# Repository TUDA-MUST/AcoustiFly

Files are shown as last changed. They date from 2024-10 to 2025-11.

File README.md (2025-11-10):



# AcoustiFly, a single transducer Acoustic Levitator






Unlock the Power of Sound: Explore Acoustic Levitation with Ease and Precision.
This project focuses on the development of an acoustic levitator, a fascinating technology capable of suspending small objects in mid-air using ultrasonic waves.
It is:
* **Low Cost:** Affordable and accessible to everyone -> approximately between 15-25 USD per unit
* **Easy to Build:** Simple setup with readily available components
* **Open Source:** Free to use, modify, and distribute
* **Mobile:** Battery powered operation possible
* **Adjustable:** Distance between transducer and reflector can be adjusted, thus stability can be tuned

This repository provides all the necessary resources, including code, schematics, and documentation, to build and experiment with your very own acoustic levitation system.

Move

***

## Table of Contents

- [Introduction](#introduction)
- [Installation](#installation)
- [Assemby](#assembly)
- [Usage](#usage)
- [Contributing](#contributing)
- [License](#license)
- [Frequently Asked Questions \(FAQ\)](#frequently-asked-questions-faq)

## Introduction

Our repository is dedicated to showcasing a method of acoustic levitation using a single transducer and a reflector. Acoustic levitation, also known as acoustic trapping, is a fascinating technique that allows objects to float in mid-air using sound waves.

In our approach, we utilize a single transducer, which emits high-frequency sound waves, and a carefully designed reflector. 
The transducer generates an acoustic field that interacts with the reflector to create standing waves within a confined region. 
These standing waves produce regions of high and low pressure, forming what is known as an "acoustic pressure node".

When an object is placed at a specific position within the acoustic pressure node, the forces exerted by the surrounding sound waves counteract the gravitational force, resulting in levitation. By precisely adjusting the distance of the transducer and the reflector, we can control the levitation height and stability of objects.

This unique approach offers several advantages. 
Firstly, it simplifies the setup by using only a single transducer and a reflector, reducing complexity and cost. 
Secondly, it enables precise control over the levitation process, allowing for manipulation and positioning of objects with great accuracy. 
Lastly, it opens up possibilities for various applications, including material handling, microfluidics, and scientific experiments.

In our repository, we provide detailed documentation, source code, and demonstrations to help you understand and implement this acoustic levitation technique.
 Whether you are a researcher, teacher, hobbyist, or enthusiast, we invite you to explore our repository, contribute to its development, and unlock the potential of acoustic levitation with a single transducer and a reflector.

**Join us on this exciting journey of harnessing the power of sound waves to defy gravity. Visit [our homepage](https://www.etit.tu-darmstadt.de/must/home_must/index.en.jsp) to delve into our research and learn more about our team.**

## Assembly
To assemble the Acoustifly you will need the following components:

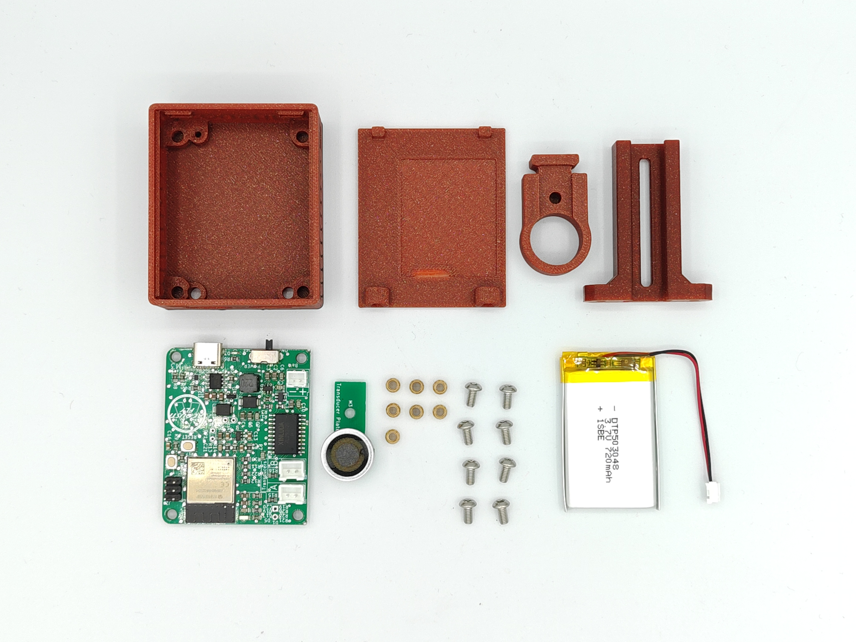
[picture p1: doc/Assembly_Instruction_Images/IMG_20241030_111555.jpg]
Acoustifly Components


* **3D-printed:**

  Base, Battery-Cover, Transducer-Holder, Vertical profile
* **Electrical Components:**

  UT-1640K-TT-2-R Transducer, Transducer PCB, Acoustifly PCB, EXP-T11-020 3.7V 720mAh Lithium Polymer Battery with JST-PH connector,
* **Others:**

  Ruthex M3s threaded inserts, M3 screws

### Instructions:
1. To install the threaded inserts you need to heat them up to 230°C. Best is to use a soldering tip to melt them into the 3D-printed parts.

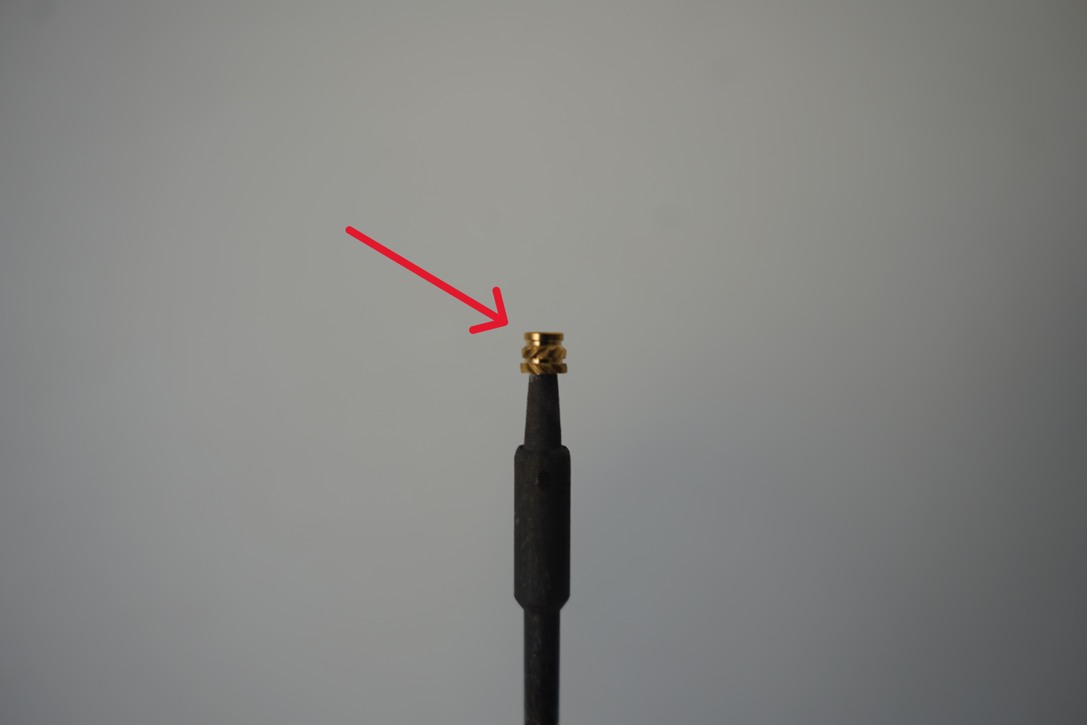
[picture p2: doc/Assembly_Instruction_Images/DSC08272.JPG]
Solderint Tip with threaded insert
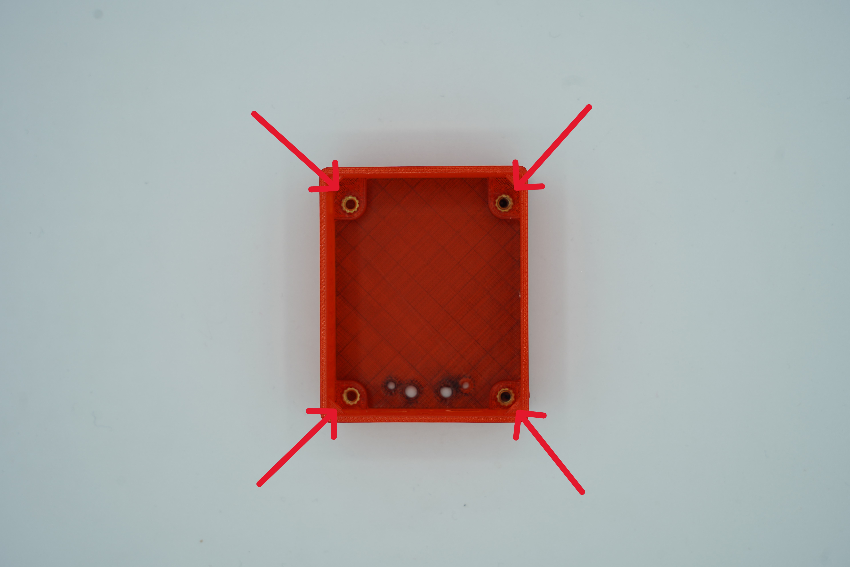
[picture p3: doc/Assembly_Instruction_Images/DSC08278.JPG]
Base with threaded insert
   
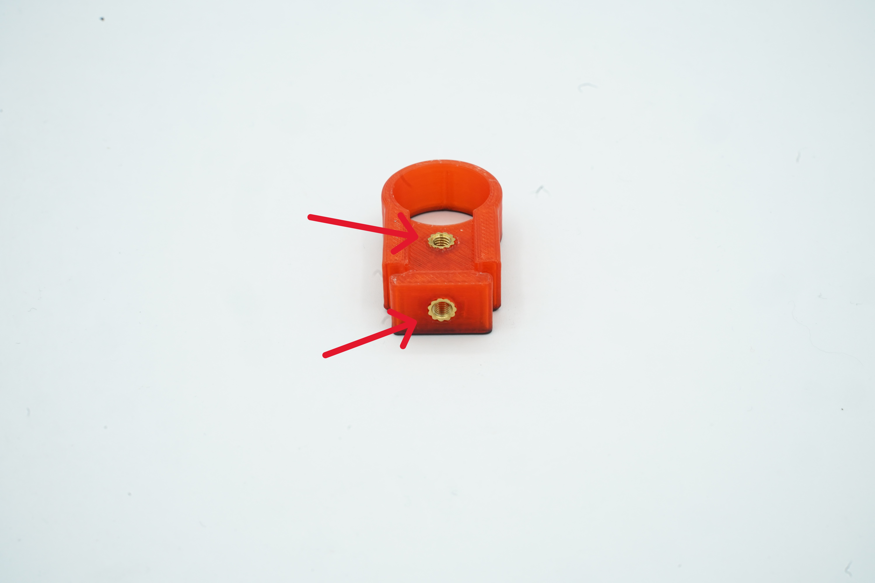
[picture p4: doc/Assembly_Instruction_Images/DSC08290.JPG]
Transducer holder with threaded inserts
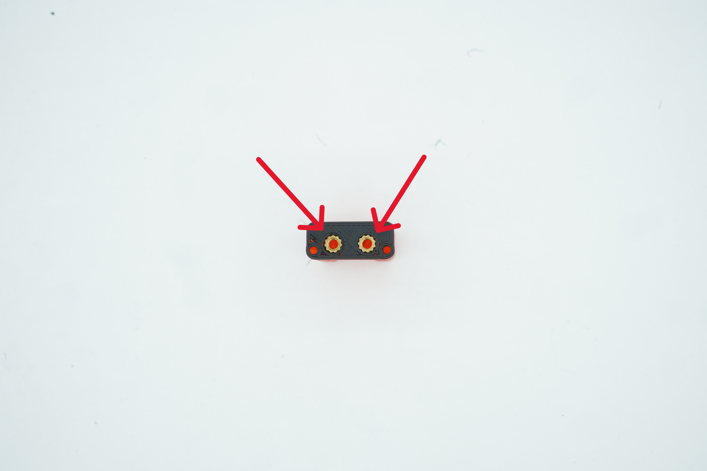
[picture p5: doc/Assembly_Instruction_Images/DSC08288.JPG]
Vertical Profile with threaded insert
   
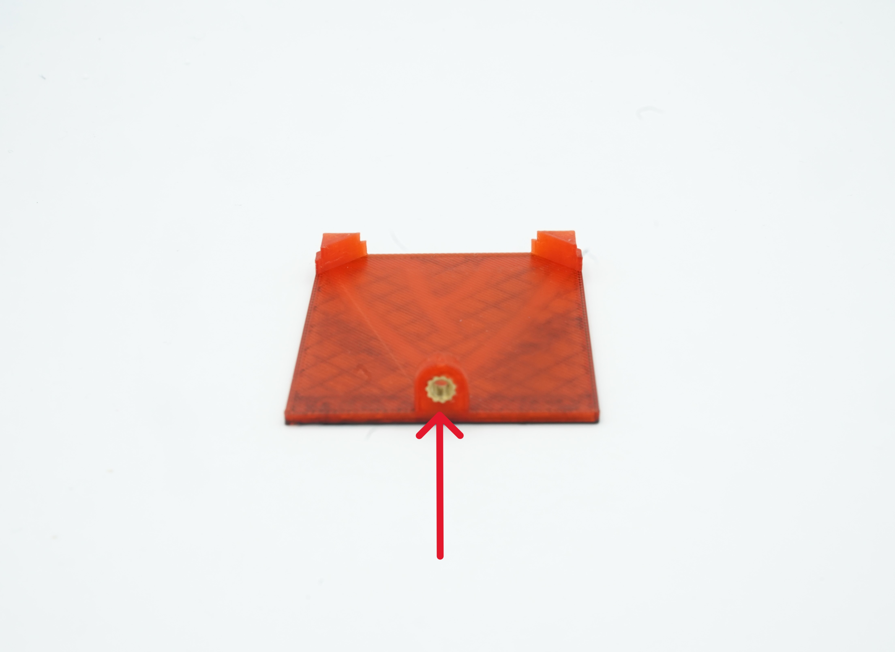
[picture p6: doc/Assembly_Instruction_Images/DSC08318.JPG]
Battery Cover with threaded insert
  

2. Mount the Transducer PCB with the Tranducer on the Transducer holder:

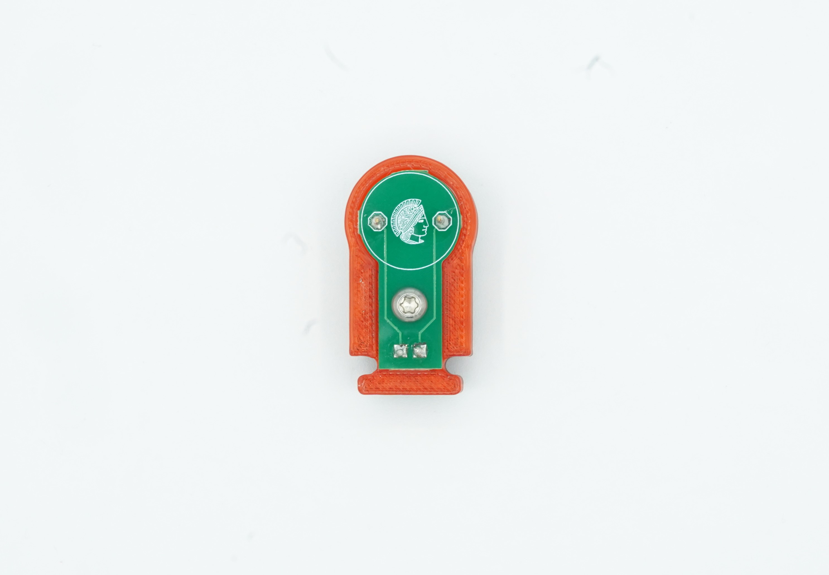
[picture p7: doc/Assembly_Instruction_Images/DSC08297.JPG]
  

3. Attach it to the vertical profile:

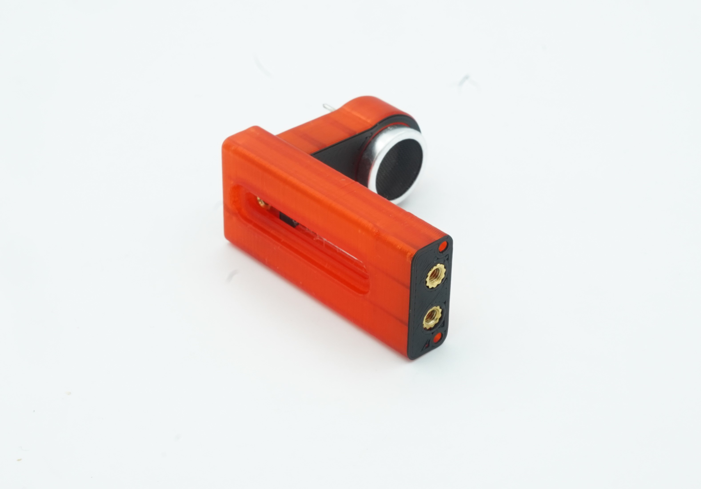
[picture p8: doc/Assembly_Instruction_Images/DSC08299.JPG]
complete transducer holder
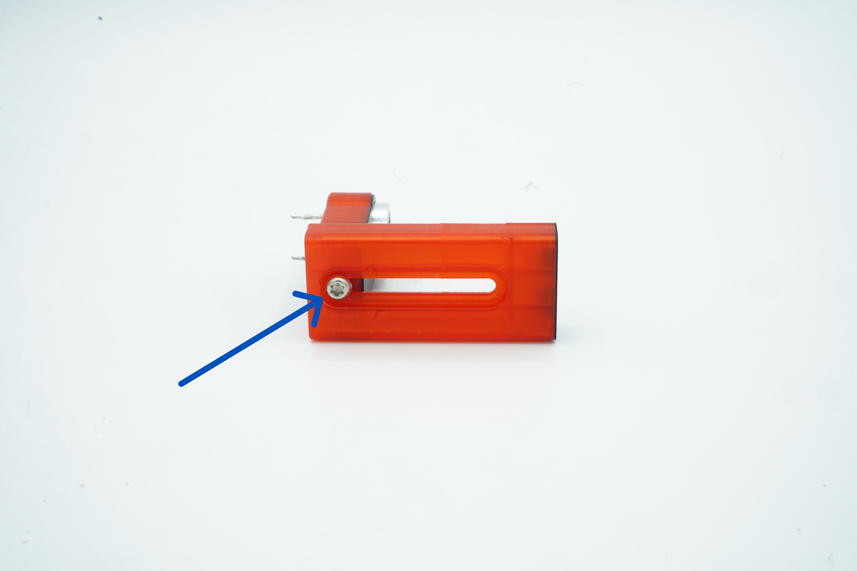
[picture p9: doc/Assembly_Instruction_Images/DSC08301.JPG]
complete transducer holder with screw
   

4. Screw the complete Tranducer Holder to the Base:

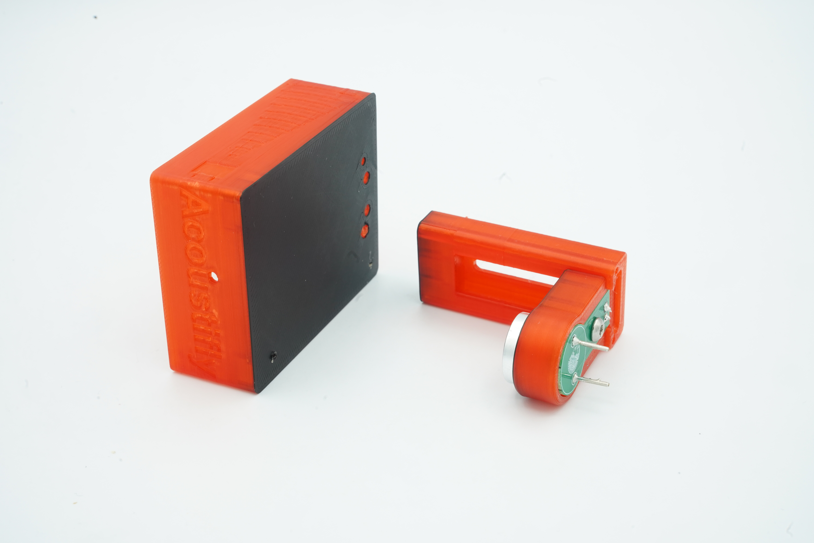
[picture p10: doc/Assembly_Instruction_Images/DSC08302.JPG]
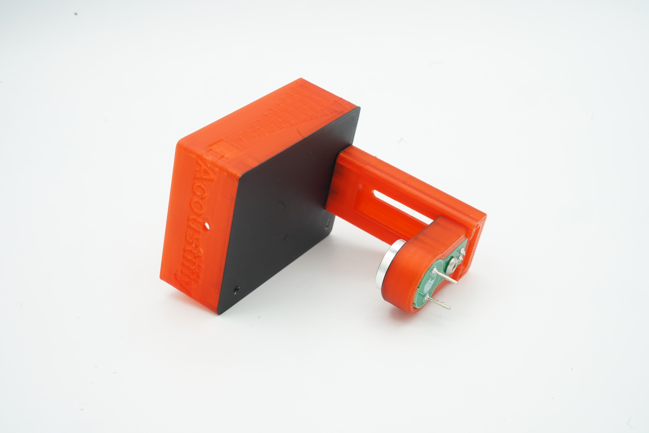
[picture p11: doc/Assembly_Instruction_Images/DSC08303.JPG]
   

5. Put the Transducer cord through the two holes on the Base and solder them to the PCB:

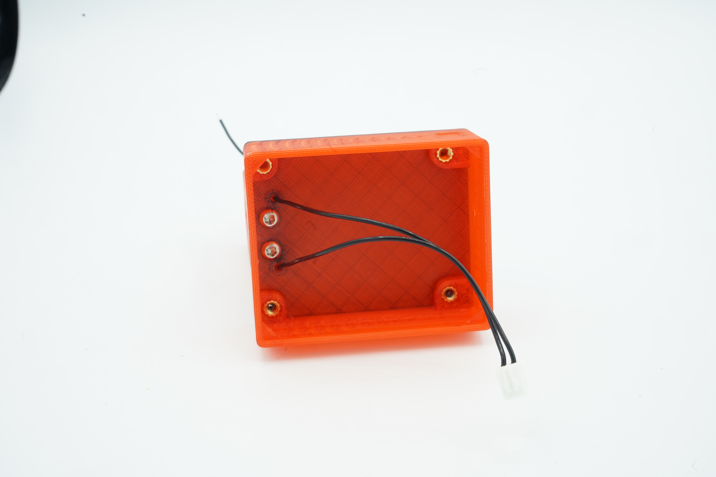
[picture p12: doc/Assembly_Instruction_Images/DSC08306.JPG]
Transducer cords
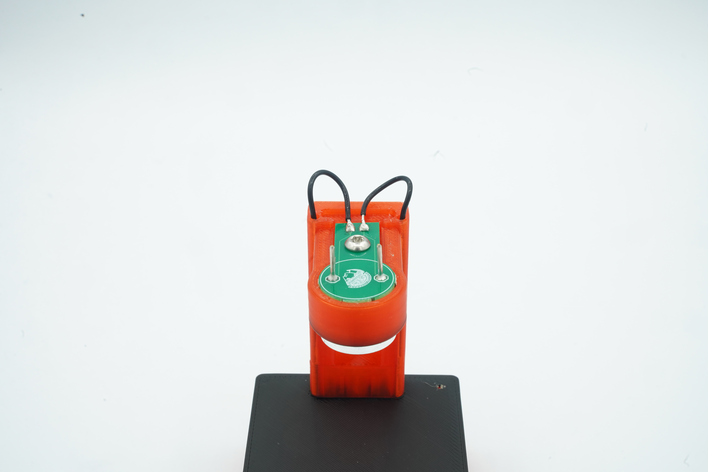
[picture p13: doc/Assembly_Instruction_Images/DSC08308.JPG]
Soldered transducer
   

6. Install the Acoustifly PCB into the Base and connect the JST-Connector. After that you can also connect the Battery-cover:

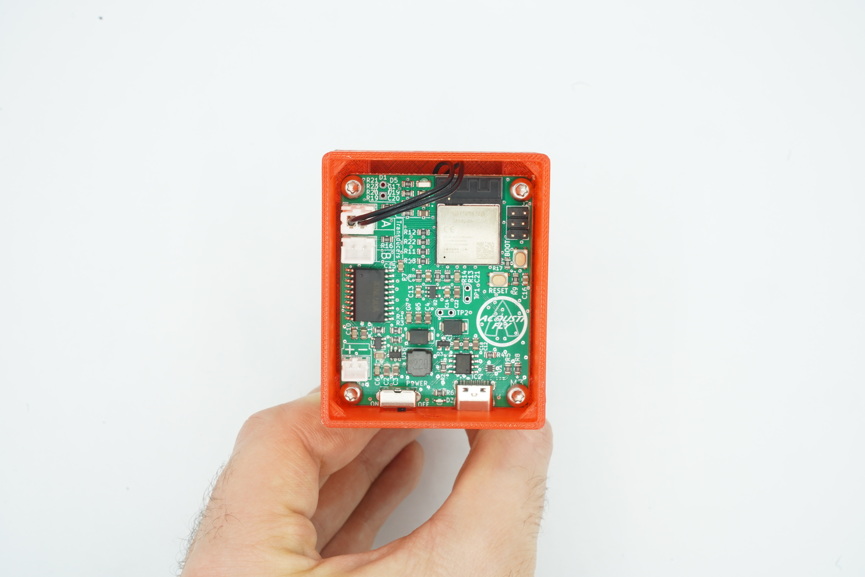
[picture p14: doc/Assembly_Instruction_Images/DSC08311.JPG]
Base with Acoustifly PCB
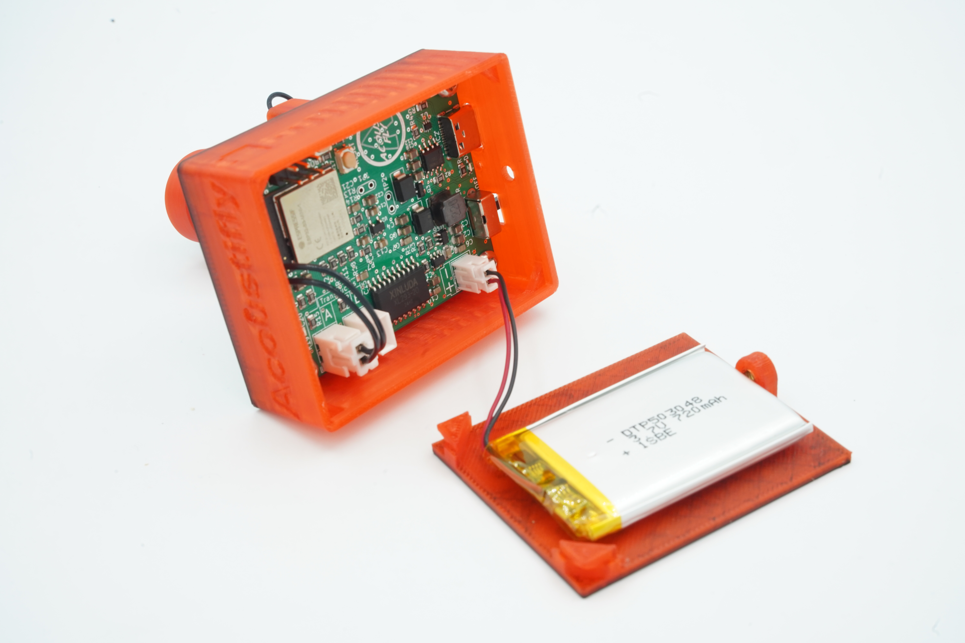
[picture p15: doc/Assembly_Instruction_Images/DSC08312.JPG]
Acoustifly open
   

7. Close the cover and enjoy your Acoustifly!:
   
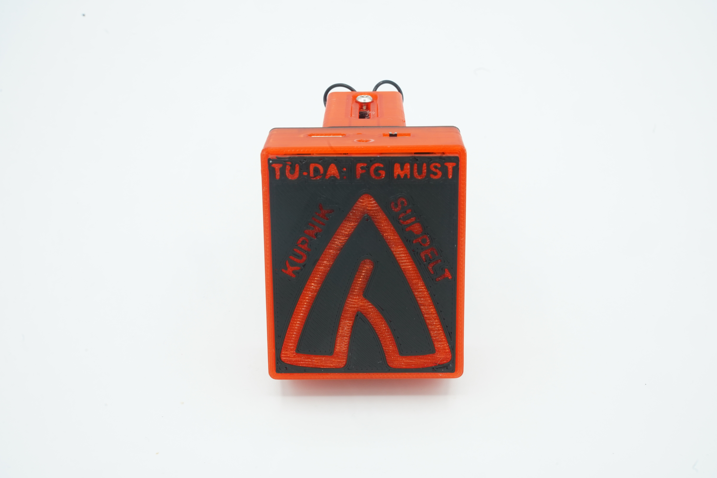
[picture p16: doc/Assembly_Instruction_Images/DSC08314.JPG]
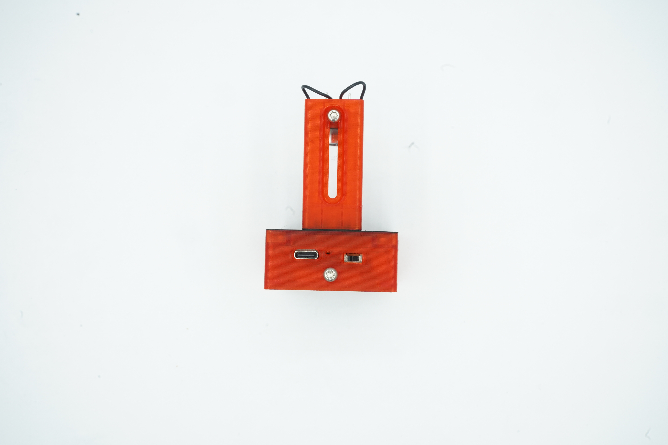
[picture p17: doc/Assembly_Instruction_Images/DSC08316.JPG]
   

## Installation

### PlatformIO
Here's a [Quickstart Guide](https://docs.platformio.org/en/latest/integration/ide/vscode.html#quick-start) on how to use Platform IO with Visual Studio Code.
### Arduino IDE
To enable working with the underlying microcontroller (ESP32-S3-MINI-1-N4R2) you are required to install the relevant board package. To do this, open _Tools > Board > Boards Manager_ and install the _'esp32'_ package by Espressif Systems.\
The Board should be set to `Adafruit Feather ESP32-S3 2MB PSRAM` as this comes closest to the used microcontroller. The relevant options under Tools should be set according to the following image. Make sure to enable `USB CDC on Boot`, which permits USB communication.

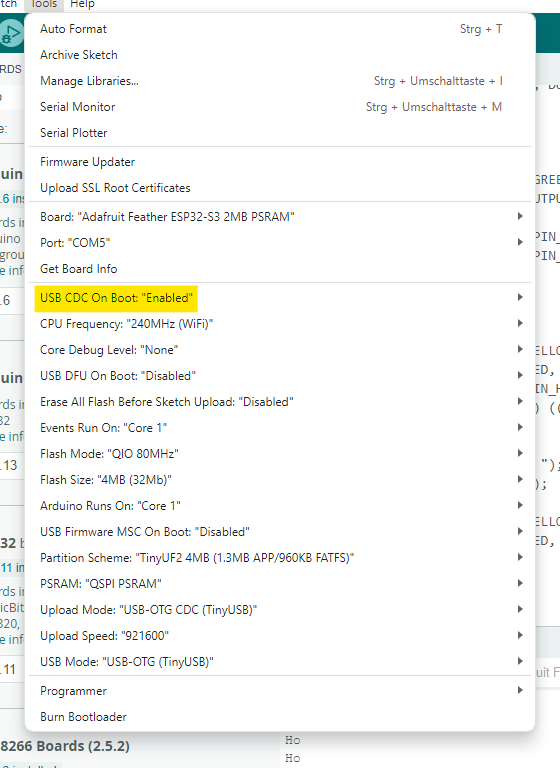
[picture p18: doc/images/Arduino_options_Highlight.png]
Arduino IDE options


### Uploading Code
Since this board does not use a separate usb-to-serial chip, the microcontroller needs to be put into the bootloading state manually. To accomplish this, simply hold down down the <kbd> BOOT </kbd> button on the PCB and then quickly press the <kbd> Reset </kbd> button once. After releasing the <kbd> BOOT </kbd> button, you are now able to upload your code.\
_! The COM Port is likely to change after entering Boot-mode and may need to be set again in your Software !_

## Usage

### Pinout
| Pin | Name | Description |
|-----|---|---|
|1|LED_YELLOWGREEN|emits yellow-green light (current sink!)|
|2|LED_RED|emits red light (current sink!)|
|4|HBRIDGE_ENABLE |HIGH enables the h_bridge/output for both transducers|
|5|HBRIDGE_A_NORMAL|PWM Input for Transducers A|
|6|HBRIDGE_A_INVERTED|inverted PWM Input for Transducers A|
|7|HBRIDGE_B_NORMAL|PWM Input for Transducers B|
|8|HBRIDGE_B_INVERTED|inverted PWM Input for Transducers B|
|9|HBRIDGE_CURRENTSENSE|read analog voltage to measure transducer current consumption|
|10|BAT_STATE |used to read battery voltage|
|40|MISO |SCPI|
|41|SCK |SCPI|
|41|MOSI |SCPI|

The **LED**s are setup in a current sink configuration, meaning a LOW signal will emit light while a HIGH signal will shut them off. Consider the command `GPIO.func_out_sel_cfg[PIN].inv_sel = 1` to reverse this. \
The **HBRIDGE_*** inputs require either the typical PWM signal or the inverted one. The easiest way to achieve this is to set both to the same [LEDC Channel](https://docs.espressif.com/projects/esp-idf/en/stable/esp32/api-reference/peripherals/ledc.html) and invert one output with the already mentioned command. \
**CURRENTSENSE** can be used to measure the current consumption of the h-bridge, so both transducers simultaneously. 
Current is measured via a 500mΩ high side shunt. 
The voltage across which is amplified by a factor of 100 and then averaged with a low pass filter. 
As a result, the average current consumption can be calculated by measuring the voltage on Pin "HBRIDGE_CURRENTSENSE" and dividing it by 50.\
**BAT_STATE** can be used to read the battery voltage. However, it is reduced by a voltage divider. Multiply the measured voltage by 11 to read the correct voltage level. \
_! As a small sidenote, the used microcontroller ESP32 does not have a very accurate, integrated ADC. However, finding the peak voltage is sufficient to determine the resonant frequency. !_

## License

This project is licensed under the GNU GENERAL PUBLIC LICENSE Version 3, 29 June 2007. Please see the [LICENSE](LICENSE) file for more details.

## Reference

If you would like to reference our project, feel free to support us by citing our research paper:\
[AcoustiFly: An Open-Source, Low-Cost Acoustic Levitator for Hands-On STEM Education](https://doi.org/10.1109/EDUCON62633.2025.11016546)
```
@inproceedings{Suppelt2025,
  title = {AcoustiFly: An Open-Source,  Low-Cost Acoustic Levitator for Hands-On STEM Education},
  url = {http://dx.doi.org/10.1109/educon62633.2025.11016546},
  DOI = {10.1109/educon62633.2025.11016546},
  booktitle = {2025 IEEE Global Engineering Education Conference (EDUCON)},
  publisher = {IEEE},
  author = {Suppelt,  Mark and Suppelt,  Sven and D\"{o}rsam,  Jan Helge and Altmann,  Alexander A. and Kupnik,  Mario},
  year = {2025},
  month = apr,
  pages = {1–5}
}
```
(or click [here](https://doi.org/10.26083/tuprints-00031137) if you want to read the paper without having to go through a paywall)

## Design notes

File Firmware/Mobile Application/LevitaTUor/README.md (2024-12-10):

# LevitaTUor

## About

This is the LevitaTUor App to control the Acoustifly using an Android Device via USB-Connection written for 
Students@School at the TU Darmstadt by Thomas Schreck

## Origin of files

This app builds upon an Andoriod Studio Drawer template and the
- [SimpleUSBTerminal by kai-morich](https://github.com/kai-morich/SimpleUsbTerminal/tree/master) 

## Known Issues

Due to how the SerialListener is handled two mayor issues are known to me:

- at the start screen the button label sometimes doesn't change from "connected" to "disconnected" when it should
- the correct return values of "Schnelleingabe" Buttons is only printed if the button is pressed twice

## Conversion

If there are some namings that I overlooked they are converted as follows:

- home -> home
- gallery -> terminal
- slideshow -> quick_access

The app is also not tested with the refactoring done, as I neither own a Smartphone with a USB-C Conntector, nor a USB-C to micro-USB Cable.

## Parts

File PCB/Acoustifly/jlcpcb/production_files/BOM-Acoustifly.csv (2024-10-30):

Comment | Designator | Footprint | LCSC
500m | RSHUNT1 | R_0805_2012Metric | C104584
SKRPABE010 | BOOT_SWITCH1,RESET_SWITCH1 | SW_SKRPABE010 | C115360
INA180A3 | U4 | SOT-23-5 | C122882
SK-12D02-VG3 | S1 | SK12D02VG3 | C136723
100k | R15,R16 | R_0805_2012Metric | C149504
D_Schottky | D2,D4 | D_SMA | C163541
TP4056 | IC2 | SOP127P600X175-9N | C16581
TYPE-C-31-M-12 | J3 | HRO_TYPE-C-31-M-12 | C165948
10k | R14,R17,R2,R9 | R_0805_2012Metric | C17414
1k | R11,R12,R13,R18,R22,R6,R7 | R_0805_2012Metric | C17513
4k7 | R4 | R_0805_2012Metric | C17673
470R | R19,R20,R21,R23,R3 | R_0805_2012Metric | C17710
JST-XH-02-PIN-LONG-PAD | X2,X4 | JST_XH_B2B-XH-A_1x02_P2.50mm_Vertical | C20079
JST-PH | X1 | JST_PH_B2B-PH-K_1x02_P2.00mm_Vertical | C2319
LED_Dual_KKA | D5 | 12-22SURSYGC_S530-A3_E2_TR8 | C264367
5k1 | R5,R8 | R_0805_2012Metric | C27834
USBLC6-2P6 | U1 | SOT-666 | C2827693
1u | C13,C14,C16,C8 | C_0805_2012Metric | C28323
DMG2305 | Q3 | SOT23-WIDE | C2940629
ESP32-S3-MINI-1-N8 | U3 | XCVR_ESP32-S3-MINI-1-N8 | C3013941
18k | R1 | R_0805_2012Metric | C316791
GCNR6045-220MC | L1 | GCNR6045-220MC | C439380
10u | C1,C11,C12,C18,C19,C2,C20,C22,C3,C4,C5 | C_0805_2012Metric | C440198
Conn_02x03_Odd_Even | J2 | PinHeader_2x03_P2.54mm_Vertical | C492420
100n | C10,C15,C17,C21,C6,C7,C9 | C_0805_2012Metric | C49678
AP2112K-3.3 | U2 | SOT-23-5 | C51118
RED_SIDE_LED | D3 | A-SP170SR6C-A01-4C | C5160727
XL293 | IC3 | SO20 | C556264
MT3608 | U6 | SOT-23-6 | C84817

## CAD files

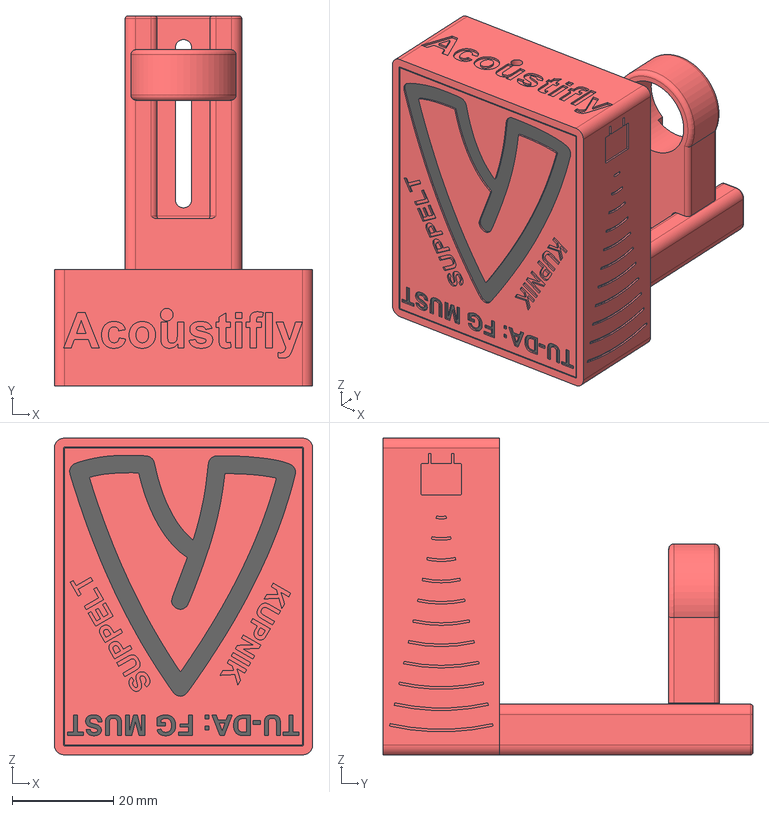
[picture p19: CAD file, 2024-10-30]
3D_Print_files/1_Col_Print/2024-06-03__Assembly.stp
51.0 x 73.0 x 62.5 mm
Base
VerticalProfile
TransducerPCB_Holder
Battery_Cover

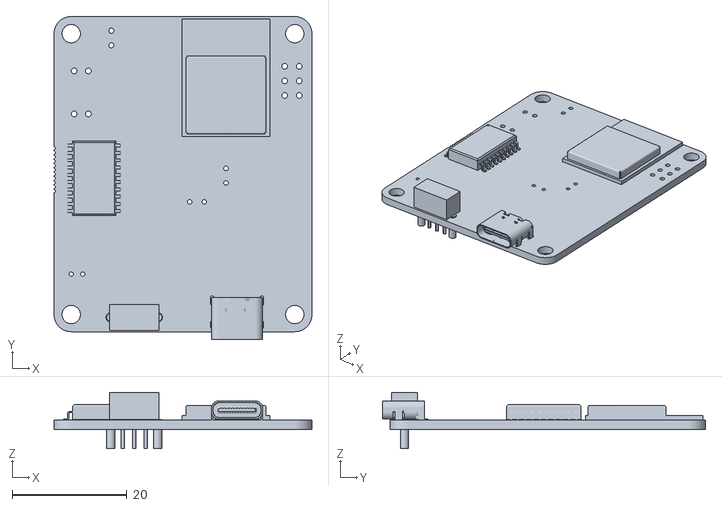
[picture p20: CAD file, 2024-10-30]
CAD/1_Col_Print/OtherParts/MainPCB_Acoustifly.stl
45.0 x 56.4 x 9.80

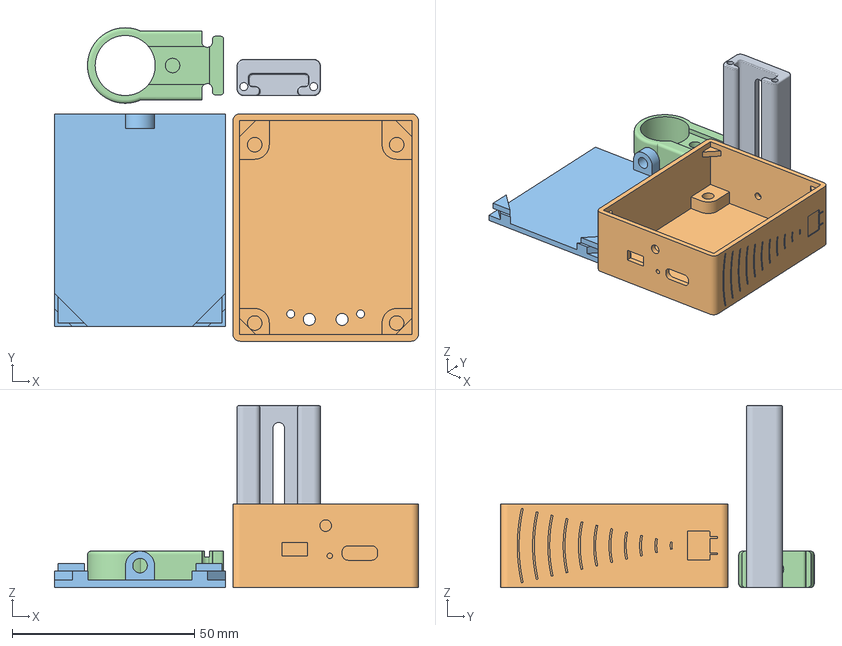
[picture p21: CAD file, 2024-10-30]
3D_Print_files/1_Col_Print/2024-06-03__1x with 1 Color Change.3mf
100.0 x 86.1 x 50.0 mm
VerticalProfile
Base
Battery_Cover
TransducerPCB_Holder

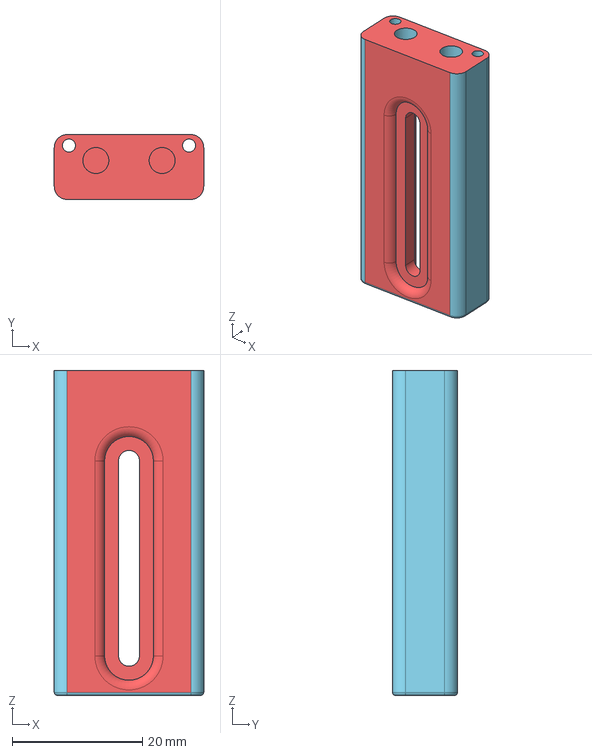
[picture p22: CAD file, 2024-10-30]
3D_Print_files/2_Col_Print/acoustifly_v8_vert-profil.stp
23.0 x 10.0 x 50.0 mm

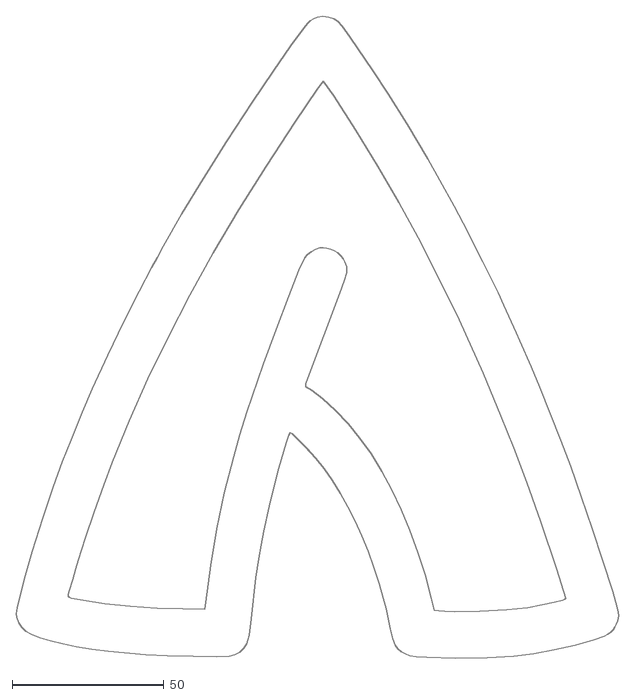
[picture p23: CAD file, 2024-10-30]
CAD/1_Col_Print/OtherParts/Acoustifly_A.dxf
198.2 x 211.3

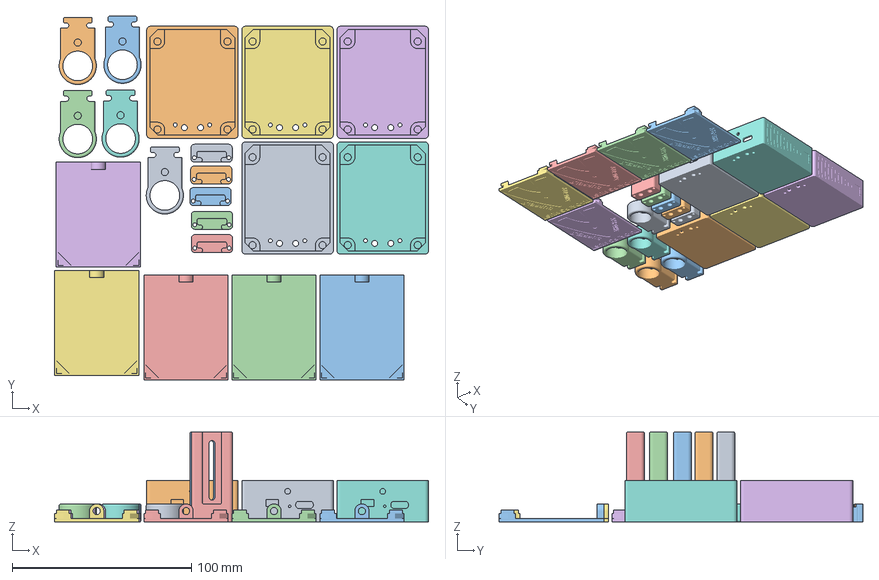
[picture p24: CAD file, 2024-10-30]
3D_Print_files/1_Col_Print/2024-06-03__5x with 1 Color Change.3mf
208.4 x 202.6 x 50.0 mm
VerticalProfile x 5
Base x 5
Battery_Cover x 5
TransducerPCB_Holder x 5

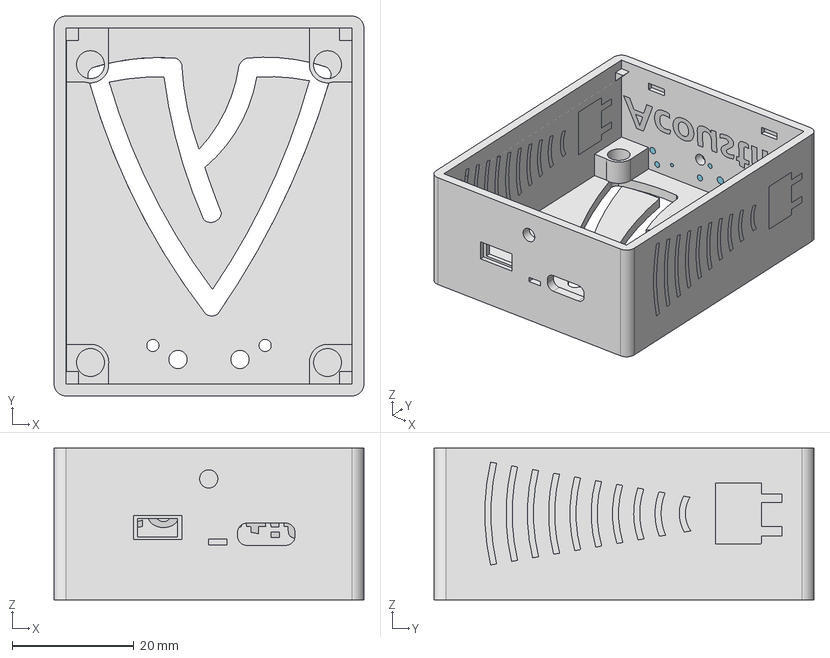
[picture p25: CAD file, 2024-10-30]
3D_Print_files/2_Col_Print/acoustifly_v8_housing.stp
51.0 x 62.5 x 25.0 mm
housing_v8
stars_front_neg
transducer_side_negativ x 2
A_v6

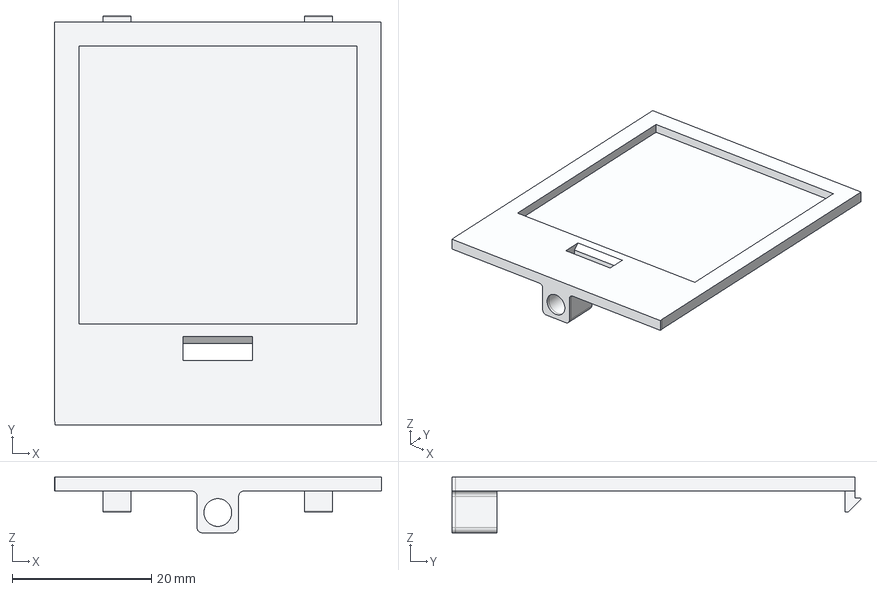
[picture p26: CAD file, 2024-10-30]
3D_Print_files/2_Col_Print/acoustifly_v8_lid.stp
47.0 x 58.8 x 8.00 mm
lid_raw
qr_code-40x40x1-6
qrcode-1708936232748

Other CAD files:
3D_Print_files/2_Col_Print/acoustifly_v8_t-holder.stp
CAD/1_Col_Print/3D-PrintedParts/Base.ipt
CAD/1_Col_Print/3D-PrintedParts/Battery_Cover.ipt
CAD/1_Col_Print/3D-PrintedParts/OldVersions/Base.0020.ipt
CAD/1_Col_Print/3D-PrintedParts/TransducerPCB_Holder.ipt
CAD/1_Col_Print/3D-PrintedParts/VerticalProfile.ipt
CAD/1_Col_Print/Assembly.iam
CAD/1_Col_Print/OtherParts/MainPCB_Acoustifly.ipt
CAD/1_Col_Print/OtherParts/Transducer16mm.ipt
CAD/1_Col_Print/OtherParts/TransducerPCB_Acoustifly.ipt

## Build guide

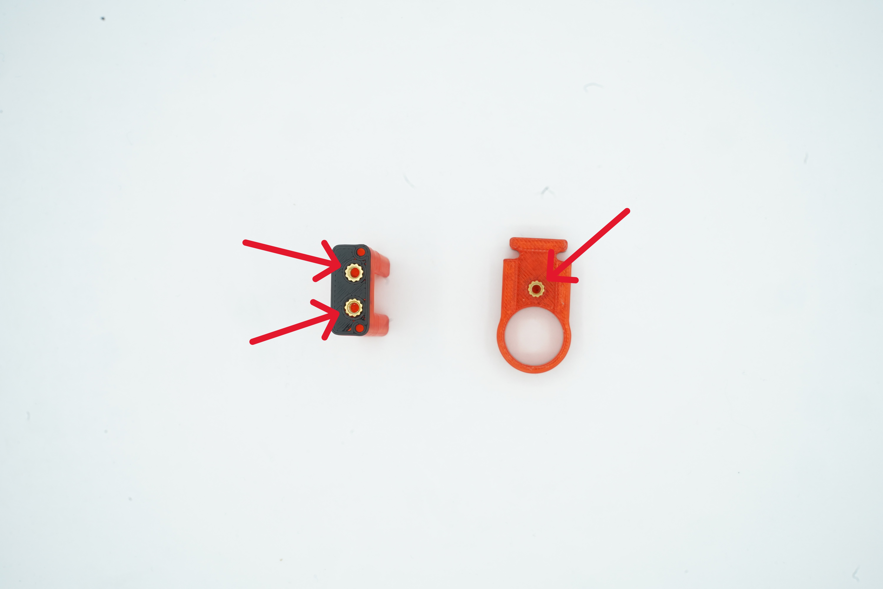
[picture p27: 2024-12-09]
doc/Assembly_Instruction_Images/DSC08287.JPG

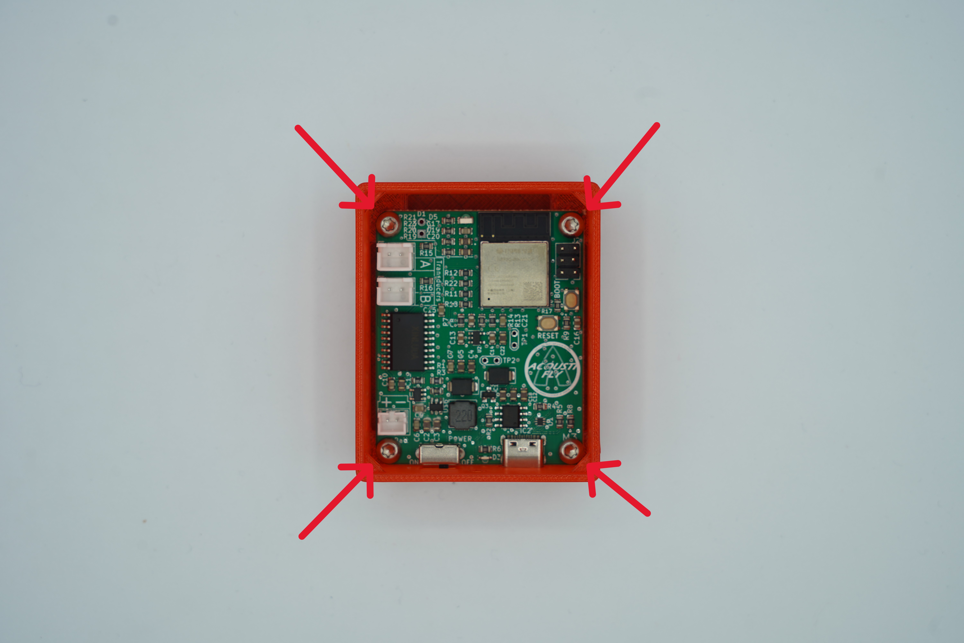
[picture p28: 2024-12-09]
doc/Assembly_Instruction_Images/DSC08280.JPG

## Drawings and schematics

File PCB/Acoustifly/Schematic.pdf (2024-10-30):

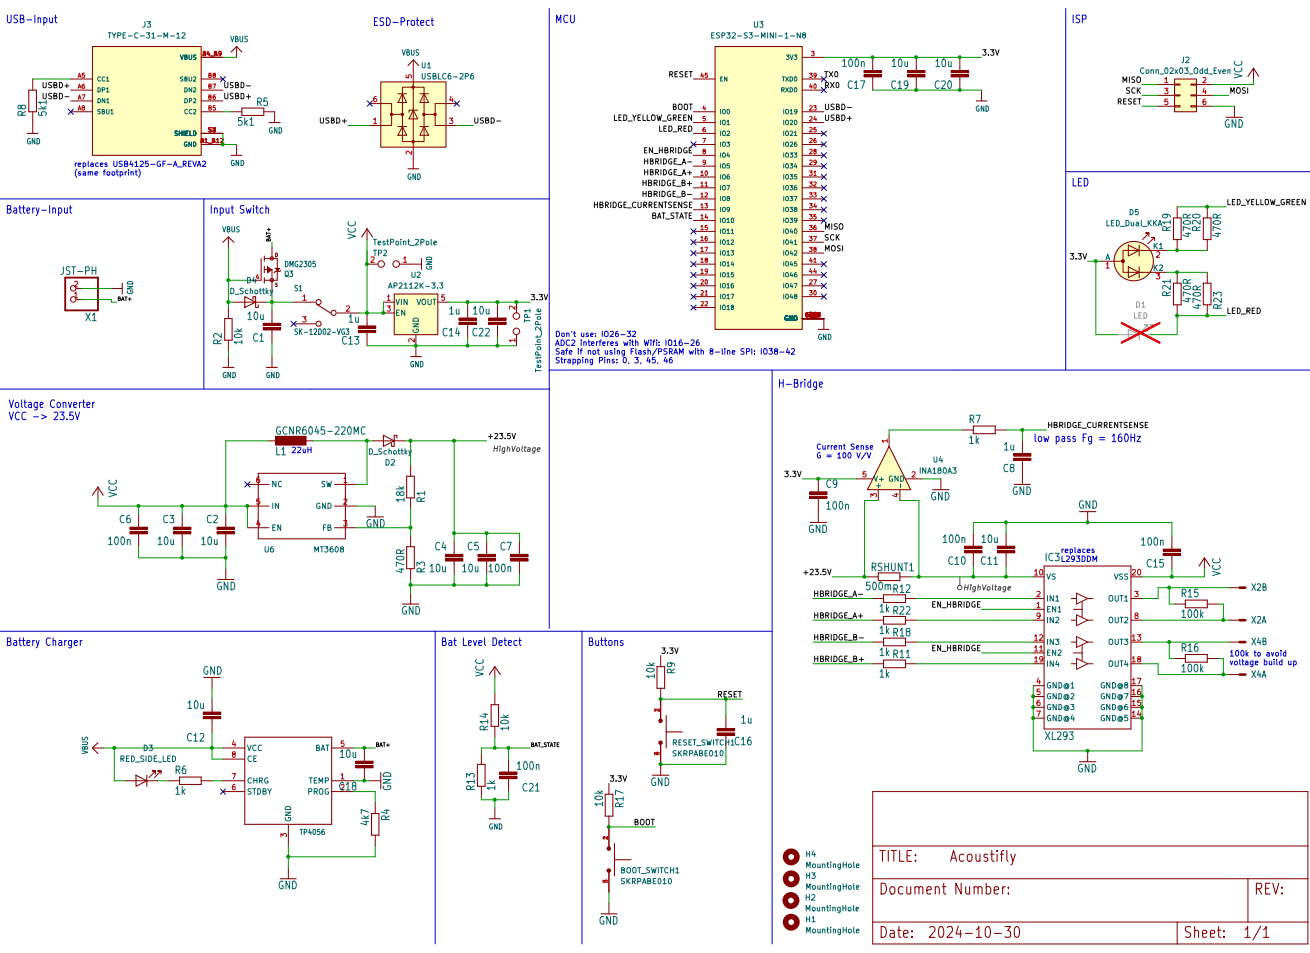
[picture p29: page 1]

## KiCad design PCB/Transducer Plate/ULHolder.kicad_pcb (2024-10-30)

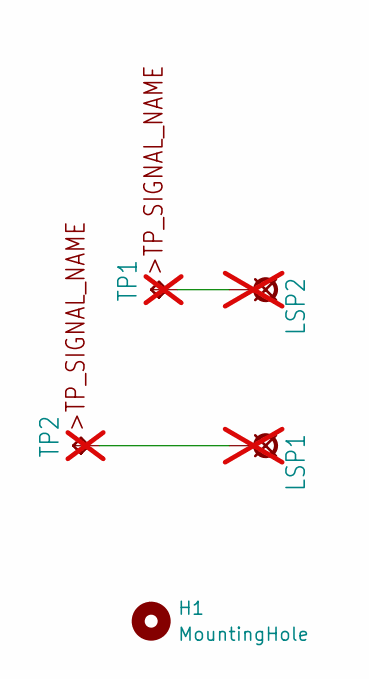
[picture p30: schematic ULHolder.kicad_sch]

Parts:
H1: MountingHole; MountingHole_3.2mm_M3
LSP1, LSP2: MCS08; not fitted
TP1, TP2: TPTP20SQ; TP20SQ; not fitted

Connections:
unnamed: LSP1.MP, TP2.TP
unnamed: LSP2.MP, TP1.TP

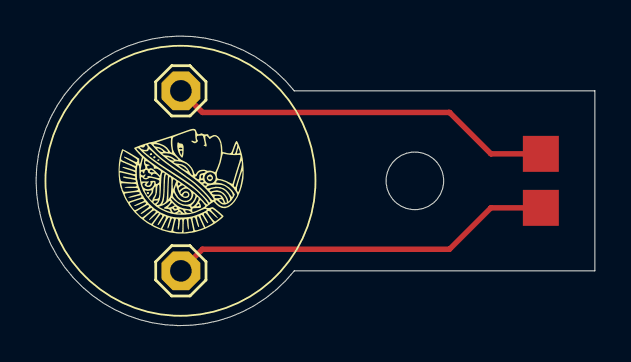
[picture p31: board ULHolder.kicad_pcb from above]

Board: 2 copper layers, 31.0 x 16.1 mm, 5 parts (0 on the bottom side), 2 nets.

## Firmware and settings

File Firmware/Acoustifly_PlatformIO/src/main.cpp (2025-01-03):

/*
How to program:
0. Connect the AcoustiFly via USB.
1. Press and hold the boot-button.
2. While holding the boot-button, also press the reset-button.
3. Release reset and afterwards release boot.
4. Now you will be able to program the board.
5. After Flashing, shortly press the reset-button for your program to start.
*/
#include <Arduino.h>
#include <stdio.h>
#include "driver/ledc.h"
#include <math.h>
#include <EEPROM.h>
#include <scpiparser.h>
#include <WiFi.h>

// PWM SETTINGS
#define PWM_FREQ_WO_CAL 40000
#define LEDC_CHANNEL 0
#define LEDC_RESOLUTION_BIT 8                                      // ! Affects ledcwrite
const int DUTY_CYCLE = (int)(pow(2, LEDC_RESOLUTION_BIT) / 2 - 1); // calculate Duty Cycle to always be at 50%

// ADC SETTINGS
#define ADC_RESOLUTION 12 // set the ADC resolution to 12 bit (standard)

// PIN DECLARATION
#define PIN_HBRIDGE_A_NORMAL 6
#define PIN_HBRIDGE_A_INVERTED 5
#define PIN_HBRIDGE_B_NORMAL 7
#define PIN_HBRIDGE_B_INVERTED 8
#define PIN_HBRIDGE_EN 4
#define PIN_HBRIDGE_CURRENTSENSE 9
#define PIN_LED_GREEN 1
#define PIN_LED_RED 2
#define PIN_BAT_STATE 10
#define PIN_MISO 40
#define PIN_SCK 41
#define PIN_MOSI 42

// Auto-Cal Settings
#define EEPROMAdresse 0
#define Mess_Wiederholungen 100

// Define Functions
long get_battery_voltage_mv();
void set_frequency(long g_freq);
long g_current_frequency = 0;

// Stuff for checking battery state
#define TIME_MS_BATTERY_CHECK 1000 // I check for battery state in 1000ms intervalls
long g_ms_time_difference_battery = 0;

//SCPI Stuff:
struct scpi_parser_context obj_ctx;

scpi_error_t scpi_identify(struct scpi_parser_context *context, struct scpi_token *command);
scpi_error_t scpi_help(struct scpi_parser_context *context, struct scpi_token *command);
scpi_error_t scpi_diag(struct scpi_parser_context *context, struct scpi_token *command);
scpi_error_t scpi_reset(struct scpi_parser_context *context, struct scpi_token *command);
scpi_error_t scpi_get_frequency(struct scpi_parser_context *context, struct scpi_token *command);
scpi_error_t scpi_get_current(struct scpi_parser_context *context, struct scpi_token *command);
scpi_error_t scpi_set_frequency(struct scpi_parser_context *context, struct scpi_token *command);
scpi_error_t scpi_set_calvalue(struct scpi_parser_context *context, struct scpi_token *command);
scpi_error_t scpi_do_pause(struct scpi_parser_context *context, struct scpi_token *command);
scpi_error_t scpi_do_movedown(struct scpi_parser_context *context, struct scpi_token *command);

void setup()
{
  // Serial Setup
  Serial.begin(115200);

  // EEPROM Setup
  EEPROM.begin(24);

  // LED SETUP
  pinMode(PIN_LED_GREEN, OUTPUT); // set LED pins to output
  pinMode(PIN_LED_RED, OUTPUT);
  digitalWrite(PIN_LED_RED, HIGH);
  GPIO.func_out_sel_cfg[PIN_LED_GREEN].inv_sel = 1; // invert the output since they are used as a current sink!
  GPIO.func_out_sel_cfg[PIN_LED_RED].inv_sel = 1;   // this way digitalWrite(HIGH) actually turns on the LED

  //SCPI Setup
  struct scpi_command* com_set;
  struct scpi_command* com_get;
  struct scpi_command* com_do;
  scpi_init(&obj_ctx);

  com_set = scpi_register_command(obj_ctx.command_tree, SCPI_CL_CHILD, "SET", 3, "S", 1, NULL);
  com_get = scpi_register_command(obj_ctx.command_tree, SCPI_CL_CHILD, "GET", 3, "G", 1, NULL);
  com_do = scpi_register_command(obj_ctx.command_tree, SCPI_CL_CHILD, "DO", 2, "D", 1, NULL);

  //SCPI Register Commands
  //Allgemein
  scpi_register_command(obj_ctx.command_tree, SCPI_CL_SAMELEVEL, "*IDN?", 5, "IDN?", 4, scpi_identify);
  scpi_register_command(obj_ctx.command_tree, SCPI_CL_SAMELEVEL, "*RST", 4, "RST", 3, scpi_reset);
  scpi_register_command(obj_ctx.command_tree, SCPI_CL_SAMELEVEL, "HELP?", 5, "HELP", 4, scpi_help);
  scpi_register_command(obj_ctx.command_tree, SCPI_CL_SAMELEVEL, "DIAG", 4, "DIA", 3, scpi_diag);
  //Set
  scpi_register_command(com_set, SCPI_CL_CHILD, "FREQUENCY", 9, "FREQ", 4, scpi_set_frequency);
  scpi_register_command(com_set, SCPI_CL_CHILD, "CALVALUE", 8, "CAL", 3, scpi_set_calvalue);
  //Get
  scpi_register_command(com_get, SCPI_CL_CHILD, "FREQUENCY", 9, "FREQ", 4, scpi_get_frequency);
  scpi_register_command(com_get, SCPI_CL_CHILD, "CURRENT", 7, "CURR", 4, scpi_get_current);
  //Do
  scpi_register_command(com_do, SCPI_CL_CHILD, "PAUSE", 5, "PA", 2, scpi_do_pause);
  scpi_register_command(com_do, SCPI_CL_CHILD, "MOVEDOWN", 8, "DOWN", 4, scpi_do_movedown);

  // PWM SETUP
  ledcSetup(LEDC_CHANNEL, PWM_FREQ_WO_CAL, LEDC_RESOLUTION_BIT); // Setup PWM Channel
  ledcAttachPin(PIN_HBRIDGE_A_NORMAL, LEDC_CHANNEL);             // attach Pins to PWM Channel
  ledcAttachPin(PIN_HBRIDGE_A_INVERTED, LEDC_CHANNEL);
  ledcAttachPin(PIN_HBRIDGE_B_NORMAL, LEDC_CHANNEL);
  ledcAttachPin(PIN_HBRIDGE_B_INVERTED, LEDC_CHANNEL);
  GPIO.func_out_sel_cfg[PIN_HBRIDGE_A_INVERTED].inv_sel = 1; // invert the output of two of the pins
  GPIO.func_out_sel_cfg[PIN_HBRIDGE_B_INVERTED].inv_sel = 1;
  pinMode(PIN_HBRIDGE_EN, OUTPUT); // enable HBRIDGE
  digitalWrite(PIN_HBRIDGE_EN, HIGH);
  ledcWrite(LEDC_CHANNEL, DUTY_CYCLE); // start PWM

  // Check if Transducer is present
  set_frequency(PWM_FREQ_WO_CAL * 0.9); // Setup Frequency to 40khz * 0.9 for baseline reading
  delay(500);
  long l_current_no_resonance = analogReadMilliVolts(PIN_HBRIDGE_CURRENTSENSE);
  set_frequency(PWM_FREQ_WO_CAL); // Setup Frequency to 40khz for baseline reading at resonace
  delay(500);
  long l_current_at_resonance = analogReadMilliVolts(PIN_HBRIDGE_CURRENTSENSE);
  Serial.print(String(F("Current at Resonance: ")) + String(l_current_at_resonance) + String(F(" - Current not at resonance: ")) + String(l_current_no_resonance));

  if (l_current_no_resonance < l_current_at_resonance * 0.9)
  { // Transducer is Present
    Serial.println(F(", i.e. Transducer should be present."));
  }
  else
  { // Transducer isnt present
    Serial.println();
    Serial.println(F("ERROR: NO TRANSDUCER DETECTED - DELETING STORED CAL-VALUES"));
    EEPROM.writeLong(EEPROMAdresse, 0);
    EEPROM.commit();
    while (analogReadMilliVolts(PIN_HBRIDGE_CURRENTSENSE) < l_current_at_resonance * 1.2)
    { // If measured Current is below te previously measured there is no Transducer installed
      Serial.println(F("ERROR: NO TRANSDUCER"));
      delay(250);
      digitalWrite(PIN_LED_RED, digitalRead(PIN_LED_RED));
    }
  }

  // Calibration-Routine, if necessary:
  long l_Actual_Measured_Current = 0;
  long l_Maximal_Measured_Current = 0;
  long l_Beste_Frequenz = 0;
  if (EEPROM.readLong(EEPROMAdresse) == 0 || EEPROM.read(EEPROMAdresse) == 255)
  { // Checks if there Calibration is neccesary
    digitalWrite(PIN_LED_RED, LOW);
    Serial.println(F("No Cal. value found - I will start calibrating now!!"));
    for (int i = 0; i < 10; i++)
    { // Blink for signalizing, that CAL will start.
      digitalWrite(PIN_LED_GREEN, digitalRead(PIN_LED_GREEN));
      delay(100);
    }
    for (int l_freq = 40500; l_freq >= 39500; l_freq = l_freq - 10)
    { // Hier kalibriere ich den Bumms in 10 Hz Schritten. This will take a while! 
      digitalWrite(PIN_LED_GREEN, digitalRead(PIN_LED_GREEN));
      set_frequency(l_freq);
      delay(2); // es wird 2ms gewartet bevor gesampelt wird
      l_Actual_Measured_Current = 0;
      for (int mess = 0; mess < Mess_Wiederholungen; mess++)
      {
        l_Actual_Measured_Current = l_Actual_Measured_Current + analogReadMilliVolts(PIN_HBRIDGE_CURRENTSENSE); // Addition aller l_Actual_Measured_Currente
        delay(10);
      }
      l_Actual_Measured_Current = l_Actual_Measured_Current / Mess_Wiederholungen; // Mittelwert wird gebildet
      Serial.println(String(F("Freq: ")) + String(l_freq) + String(F(" Current: ")) + String(l_Actual_Measured_Current));
      if (l_Actual_Measured_Current > l_Maximal_Measured_Current)
      {
        l_Maximal_Measured_Current = l_Actual_Measured_Current;
        l_Beste_Frequenz = l_freq;
      }
    }
    Serial.println(String(F("Best Freq: ")) + String(l_Beste_Frequenz) + String(F(" with current: ")) + String(l_Maximal_Measured_Current));
    EEPROM.writeLong(EEPROMAdresse, l_Beste_Frequenz);
    EEPROM.commit();
    delay(500);
  }

  // Finally turn levitator on. I avoid bifurcation by sweeping the frequency down.
  long l_cal_freq = EEPROM.readLong(EEPROMAdresse);
  Serial.println(String(F("Stored Cal. value is: ")) + String(l_cal_freq));
  delay(100);
  digitalWrite(PIN_LED_GREEN, LOW);
  for (int l_freq = 42000; l_freq >= l_cal_freq; l_freq = l_freq - 25)
  {
    set_frequency(l_freq); // Setup PWM Channel
    delay(1);
  }
  set_frequency(EEPROM.readLong(EEPROMAdresse));
  digitalWrite(PIN_LED_GREEN, HIGH);
  digitalWrite(PIN_LED_RED, LOW);
  Serial.println(F("Welcome to Acoustifly!"));
  Serial.println(F("Print HELP? to see all available commands."));
}

void loop()
{
  //Determine if Serial Data for detecting SCPI Data is available:
  if (Serial.available() > 0) //Hier schaue ich ob Serielle Daten Kommen & wenn ja dann wird der Befehl nach SCPI durchsucht
  {
    char line_buffer[128];
    unsigned char read_length;
    /* Read in a line and execute it. */
    read_length = Serial.readBytesUntil('\n', line_buffer, 128);
    if (read_length > 0)
    {
      scpi_execute_command(&obj_ctx, line_buffer, read_length);
    }
  }

  //This is for determining Battery-State: 
  if (g_ms_time_difference_battery > millis())
  {
    g_ms_time_difference_battery = millis();
  }
  if (millis() - g_ms_time_difference_battery > TIME_MS_BATTERY_CHECK)
  {
    g_ms_time_difference_battery = millis();
    long l_batteryvoltage_mv = get_battery_voltage_mv();
    //Serial.println(String(l_batteryvoltage_mv) + " ; " + String(analogReadMilliVolts(PIN_HBRIDGE_CURRENTSENSE)));
    if (l_batteryvoltage_mv < 3200) //Battery is fucking low -> Turn of Levitation
    {
      digitalWrite(PIN_HBRIDGE_EN, LOW);
      digitalWrite(PIN_LED_GREEN, LOW);
      bool quit = false;
      while (quit == false)
      {
        digitalWrite(PIN_LED_RED, digitalRead(PIN_LED_RED));
        delay(100);
        if (get_battery_voltage_mv() > 3800)
        {
          quit = true;
        }
      }
      digitalWrite(PIN_HBRIDGE_EN, HIGH);
      digitalWrite(PIN_LED_GREEN, HIGH);
    }
    else if (l_batteryvoltage_mv < 3500) //Battery will soon run out, indicate that
    {
      digitalWrite(PIN_LED_RED, digitalRead(PIN_LED_RED));
      digitalWrite(PIN_LED_GREEN, digitalRead(PIN_LED_GREEN));
    }
    else //Battery State is ok. 
    {
      digitalWrite(PIN_LED_GREEN, HIGH);
      digitalWrite(PIN_LED_RED, LOW);
    }
  }
}

// Functions:
long get_battery_voltage_mv()
{
  return analogReadMilliVolts(PIN_BAT_STATE) * 11 + 200;
}

void set_frequency(long g_freq)
{
  ledcSetup(LEDC_CHANNEL, g_freq, LEDC_RESOLUTION_BIT);
  g_current_frequency = g_freq;
}

void printSerialError(){
  Serial.println("ERROR");
}

//Antwortet auf *IDN?
scpi_error_t scpi_identify(struct scpi_parser_context *context, struct scpi_token *command)
{
  scpi_free_tokens(command);

  Serial.println(F("This is Acoustifly!"));
  Serial.println(F("Made by Measurement and Sensor Technology Group at TU Darmstadt"));
  Serial.println(F("https://www.etit.tu-darmstadt.de/must/home_must/index.de.jsp"));
  Serial.println(F("This is a project of Sven Suppelt"));
  Serial.println(F("https://de.linkedin.com/in/sven-suppelt-81b604190"));
  Serial.println(F("Software Date: 11.09.2024"));
  return SCPI_SUCCESS;
}

//Reset the device
scpi_error_t scpi_reset(struct scpi_parser_context *context, struct scpi_token *command)
{
  scpi_free_tokens(command);
  Serial.println(F("Resetting the device as well as the cal. value."));
  Serial.println(F("Goodbye!"));
  EEPROM.writeLong(EEPROMAdresse, 0);
  EEPROM.commit();
  ESP.restart();
  return SCPI_SUCCESS;
}

//Antwortet auf help?
scpi_error_t scpi_help(struct scpi_parser_context *context, struct scpi_token *command)
{
  scpi_free_tokens(command);
  Serial.println(F("Available Commands:"));
  Serial.println(F("*IDN?  -  Returns Identification."));
  Serial.println(F("*RST   -  Restarts the device and deletes its cal. value."));
  Serial.println(F("HELP?  -  Returns this text."));
  Serial.println(F("DIAG   -  Returns Diagnostic Information."));
  Serial.println(F(":SET:FREQUENCY XXXX   -  Sets the H-Bridge Frequency to this Value (XXXX). Unit is Hz. Allowed 30000 - 50000.")); 
  Serial.println(F(":SET:CALVALUE XXXX   -  Sets the CalValue to this Value (XXXX). Unit is Hz. Allowed 30000 - 50000. Warning: Not Recommended!"));
  Serial.println(F(":GET:FREQUENCY  -   Returns the current Frequency."));
  Serial.println(F(":GET:CURRENT   -   Measures the current and returns it."));
  Serial.println(F(":DO:PAUSE XXXX  -  Pauses the Output for the given time XXXX in ms. Allowed 0 - 1000."));
  Serial.println(F(":DO:MOVEDOWN   -   Tries to do a MoveDown with values calculated by the free fall equations."));
  Serial.println(F("------------------"));
  Serial.println(F("ATTENTION: PLEASE WRITE EVERYTHING IN CAPS."));
  // Serial.println(F("Commands are in SCPI-Notation, meaning, you can write :DO:MOVEDOWN or :D:DOWN ."));
  // Serial.println(F("I.e. everything that is not caps is optional!"));
  return SCPI_SUCCESS;
}

//Print Diag. Info
scpi_error_t scpi_diag(struct scpi_parser_context *context, struct scpi_token *command)
{
  scpi_free_tokens(command);

  Serial.println(String(F("Current frequency: ")) + String(g_current_frequency));
  Serial.println(String(F("Battery state (mV): ")) + String(get_battery_voltage_mv()));
  Serial.println(String(F("Current: ")) + String(analogReadMilliVolts(PIN_HBRIDGE_CURRENTSENSE)));
  Serial.println(String(F("Stored Cal. value: ")) + String(EEPROM.readLong(EEPROMAdresse)));
  Serial.println(String(F("Uptime (ms): ")) + String(millis()));
  Serial.println(String(F("ESP Board MAC Address: ")) + String(WiFi.macAddress()));
  return SCPI_SUCCESS;
}

//Set Frequency
scpi_error_t scpi_set_frequency(struct scpi_parser_context* context, struct scpi_token* command)
{
  struct scpi_token* args;
  struct scpi_numeric output_numeric;
  unsigned char output_value;

  args = command;

  while (args != NULL && args->type == 0)
  {
    args = args->next;
  }

  output_numeric = scpi_parse_numeric(args->value, args->length, 1e3, 0, 25e6);
  if (output_numeric.length == 0 ||
      (output_numeric.length == 2 && output_numeric.unit[0] == 'H' && output_numeric.unit[1] == 'z'))
  {
    double input = output_numeric.value;
    if (input > 30000 && input < 50000) {
      set_frequency(input);
      Serial.println("OK");
    }
    else {
      printSerialError();
    }
  }
  else
  {
    printSerialError();
    scpi_error error;
    error.id = -200;
    error.description = "Invalid unit";
    error.length = 26;

    scpi_queue_error(&obj_ctx, error);
    scpi_free_tokens(command);
    return SCPI_SUCCESS;
  }

  scpi_free_tokens(command);

  return SCPI_SUCCESS;
}

//Set Cal Value
scpi_error_t scpi_set_calvalue(struct scpi_parser_context* context, struct scpi_token* command)
{
  struct scpi_token* args;
  struct scpi_numeric output_numeric;
  unsigned char output_value;

  args = command;

  while (args != NULL && args->type == 0)
  {
    args = args->next;
  }

  output_numeric = scpi_parse_numeric(args->value, args->length, 1e3, 0, 25e6);
  if (output_numeric.length == 0 ||
      (output_numeric.length == 2 && output_numeric.unit[0] == 'H' && output_numeric.unit[1] == 'z'))
  {
    double input = output_numeric.value;
    if (input > 30000 && input < 50000) {
      EEPROM.writeLong(EEPROMAdresse, input);
      EEPROM.commit();
      Serial.println("OK");
    }
    else {
      printSerialError();
    }
  }
  else
  {
    printSerialError();
    scpi_error error;
    error.id = -200;
    error.description = "Invalid unit";
    error.length = 26;

    scpi_queue_error(&obj_ctx, error);
    scpi_free_tokens(command);
    return SCPI_SUCCESS;
  }

  scpi_free_tokens(command);

  return SCPI_SUCCESS;
}

//Gibt die Aktuell eingestellte Frequenz zurück
scpi_error_t scpi_get_frequency(struct scpi_parser_context* context, struct scpi_token* command)
{
  Serial.println(g_current_frequency);
  scpi_free_tokens(command);
  return SCPI_SUCCESS;
}

//Gibt die Aktuellen Current zurück
scpi_error_t scpi_get_current(struct scpi_parser_context* context, struct scpi_token* command)
{
  Serial.println(analogReadMilliVolts(PIN_HBRIDGE_CURRENTSENSE));
  scpi_free_tokens(command);
  return SCPI_SUCCESS;
}

//Do Pause
scpi_error_t scpi_do_pause(struct scpi_parser_context* context, struct scpi_token* command)
{
  struct scpi_token* args;
  struct scpi_numeric output_numeric;
  unsigned char output_value;

  args = command;

  while (args != NULL && args->type == 0)
  {
    args = args->next;
  }

  output_numeric = scpi_parse_numeric(args->value, args->length, 1e3, 0, 25e6);
  if (output_numeric.length == 0 ||
      (output_numeric.length == 2 && output_numeric.unit[0] == 'H' && output_numeric.unit[1] == 'z'))
  {
    double input = output_numeric.value;
    if (input > 0 && input < 1000) {
      digitalWrite(PIN_LED_GREEN, LOW);
      digitalWrite(PIN_LED_RED, HIGH);
      digitalWrite(PIN_HBRIDGE_EN, LOW);
      delay(input);
      digitalWrite(PIN_HBRIDGE_EN, HIGH);
      digitalWrite(PIN_LED_GREEN, HIGH);
      digitalWrite(PIN_LED_RED, LOW);
      Serial.println("OK");
    }
    else {
      printSerialError();
    }
  }
  else
  {
    printSerialError();
    scpi_error error;
    error.id = -200;
    error.description = "Invalid unit";
    error.length = 26;

    scpi_queue_error(&obj_ctx, error);
    scpi_free_tokens(command);
    return SCPI_SUCCESS;
  }

  scpi_free_tokens(command);

  return SCPI_SUCCESS;
}

//Do MoveDown
scpi_error_t scpi_do_movedown(struct scpi_parser_context* context, struct scpi_token* command)
{
  scpi_free_tokens(command);
  //Values from calculating the free-fall distance
  digitalWrite(PIN_LED_GREEN, LOW);
  digitalWrite(PIN_LED_RED, HIGH);
  digitalWrite(PIN_HBRIDGE_EN, LOW);
  delayMicroseconds(29579);
  digitalWrite(PIN_HBRIDGE_EN, HIGH);
  digitalWrite(PIN_LED_GREEN, HIGH);
  digitalWrite(PIN_LED_RED, LOW);
  Serial.println("OK");
  return SCPI_SUCCESS;
}

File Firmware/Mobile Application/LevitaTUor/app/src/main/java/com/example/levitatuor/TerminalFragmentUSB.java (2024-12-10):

package com.example.levitatuor;

import android.Manifest;
import android.app.Activity;
import android.app.AlertDialog;
import android.app.PendingIntent;
import android.content.BroadcastReceiver;
import android.content.ComponentName;
import android.content.Context;
import android.content.Intent;
import android.content.IntentFilter;
import android.content.ServiceConnection;
import android.hardware.usb.UsbDevice;
import android.hardware.usb.UsbDeviceConnection;
import android.hardware.usb.UsbManager;
import android.os.Build;
import android.os.Bundle;
import android.os.Handler;
import android.os.IBinder;
import android.os.Looper;
import android.text.Editable;
import android.text.Spannable;
import android.text.SpannableStringBuilder;
import android.text.method.ScrollingMovementMethod;
import android.text.style.ForegroundColorSpan;
import android.view.LayoutInflater;
import android.view.Menu;
import android.view.View;
import android.view.ViewGroup;
import android.widget.Button;
import android.widget.TextView;
import android.widget.Toast;
import android.widget.ToggleButton;

import androidx.annotation.NonNull;
import androidx.annotation.Nullable;
import androidx.core.content.ContextCompat;
import androidx.fragment.app.Fragment;

import com.hoho.android.usbserial.driver.SerialTimeoutException;
import com.hoho.android.usbserial.driver.UsbSerialDriver;
import com.hoho.android.usbserial.driver.UsbSerialPort;
import com.hoho.android.usbserial.driver.UsbSerialProber;
import com.hoho.android.usbserial.util.XonXoffFilter;

import java.io.IOException;
import java.util.ArrayDeque;
import java.util.ArrayList;
import java.util.Arrays;
import java.util.EnumSet;

public class TerminalFragmentUSB extends Fragment implements ServiceConnection, SerialListener {

    private enum Connected { False, Pending, True }

    private final Handler mainLooper;
    private final BroadcastReceiver broadcastReceiver;
    private int deviceId, portNum, baudRate;
    private UsbSerialPort usbSerialPort;
    private SerialService service;

    private TextView receiveText;
    private TextView sendText;
    private Button sendBtn;
    private TextUtil.HexWatcher hexWatcher;

    private Connected connected = Connected.False;
    private boolean initialStart = true;
    private boolean hexEnabled = false;
    private enum SendButtonState {Idle, Busy, Disabled};

    private ControlLines controlLines = new ControlLines();
    private XonXoffFilter flowControlFilter;

    private boolean pendingNewline = false;
    private String newline = TextUtil.newline_lf;
    private SpannableStringBuilder buttonBuffer;

    public TerminalFragmentUSB() {
        mainLooper = new Handler(Looper.getMainLooper());
        broadcastReceiver = new BroadcastReceiver() {
            @Override
            public void onReceive(Context context, Intent intent) {
                if(Constants.INTENT_ACTION_GRANT_USB.equals(intent.getAction())) {
                    Boolean granted = intent.getBooleanExtra(UsbManager.EXTRA_PERMISSION_GRANTED, false);
                    connect(granted);
                }
            }
        };
        buttonBuffer = new SpannableStringBuilder();
    }

    /*
     * Lifecycle
     */
    @Override
    public void onCreate(@Nullable Bundle savedInstanceState) {
        super.onCreate(savedInstanceState);
        setHasOptionsMenu(true);
        setRetainInstance(true);
        deviceId = getArguments().getInt("device");
        portNum = getArguments().getInt("port");
        baudRate = getArguments().getInt("baud");
    }

    @Override
    public void onDestroy() {
        if (connected != Connected.False)
            disconnect();
        getActivity().stopService(new Intent(getActivity(), SerialService.class));
        super.onDestroy();
    }

    @Override
    public void onStart() {
        super.onStart();
        if(service != null)
            service.attach(this);
        else
            getActivity().startService(new Intent(getActivity(), SerialService.class)); // prevents service destroy on unbind from recreated activity caused by orientation change
        ContextCompat.registerReceiver(getActivity(), broadcastReceiver, new IntentFilter(Constants.INTENT_ACTION_GRANT_USB), ContextCompat.RECEIVER_NOT_EXPORTED);
    }

    @Override
    public void onStop() {
        getActivity().unregisterReceiver(broadcastReceiver);
        if(service != null && !getActivity().isChangingConfigurations())
            service.detach();
        super.onStop();
    }

    @SuppressWarnings("deprecation") // onAttach(context) was added with API 23. onAttach(activity) works for all API versions
    @Override
    public void onAttach(@NonNull Activity activity) {
        super.onAttach(activity);
        getActivity().bindService(new Intent(getActivity(), SerialService.class), this, Context.BIND_AUTO_CREATE);
    }

    @Override
    public void onDetach() {
        try { getActivity().unbindService(this); } catch(Exception ignored) {}
        super.onDetach();
    }

    @Override
    public void onResume() {
        super.onResume();
        if(initialStart && service != null) {
            initialStart = false;
            getActivity().runOnUiThread(this::connect);
        }
        if(connected == Connected.True)
            controlLines.start();
    }

    @Override
    public void onPause() {
        controlLines.stop();
        super.onPause();
    }

    @Override
    public void onServiceConnected(ComponentName name, IBinder binder) {
        service = ((SerialService.SerialBinder) binder).getService();
        service.attach(this);
        if(initialStart && isResumed()) {
            initialStart = false;
            getActivity().runOnUiThread(this::connect);
        }
    }

    @Override
    public void onServiceDisconnected(ComponentName name) {
        service = null;
    }

    /*
     * UI
     */
    @Override
    public View onCreateView(@NonNull LayoutInflater inflater, ViewGroup container, Bundle savedInstanceState) {
        View view = inflater.inflate(R.layout.fragment_terminal, container, false);
        receiveText = view.findViewById(R.id.serial_monitor_in);            // TextView performance decreases with number of spans
        receiveText.setTextColor(getResources().getColor(R.color.colorRecieveText)); // set as default color to reduce number of spans
        receiveText.setMovementMethod(ScrollingMovementMethod.getInstance());

        sendText = view.findViewById(R.id.insertFreeText);
        sendBtn = view.findViewById(R.id.sendSerialLine);
        hexWatcher = new TextUtil.HexWatcher(sendText);
        hexWatcher.enable(hexEnabled);
        sendText.addTextChangedListener(hexWatcher);
        sendText.setHint(hexEnabled ? "HEX mode" : "");

        View sendBtn = view.findViewById(R.id.sendSerialLine);
        sendBtn.setOnClickListener(v -> send(sendText.getText().toString()));
        //controlLines.onCreateView(view);
        return view;
    }
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

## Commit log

2024-12-09 Added Assembly Instructions
2024-12-10 added mobile application
    [app_bar_main.xml]
